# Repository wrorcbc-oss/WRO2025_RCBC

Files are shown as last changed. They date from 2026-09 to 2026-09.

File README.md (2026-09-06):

# WRO2026_RPRC
# 🚀 WRO 2026 Future Engineers – RPRC

<center>
<p align="center">
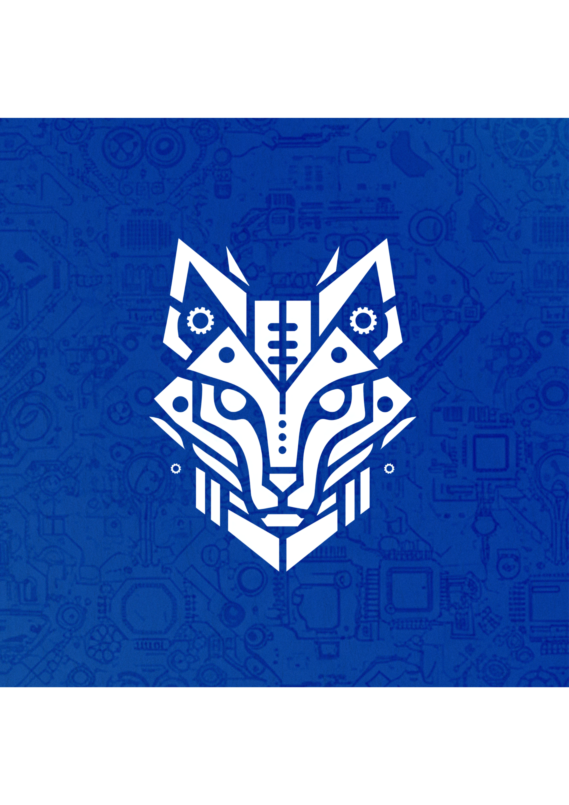
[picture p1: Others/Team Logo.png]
Team Logo
  
</p>


</center>

---

## **EGPYTIAN NATIONAL TEAM **

Welcome to the GitHub repository of Team RPRC, competing in the World Robot Olympiad™ (WRO®) Future Engineers 2025 category. Our team is made up of Egyptian students who have designed a compact, innovative, and autonomous self-driving vehicle to tackle the dynamic challenges of the WRO 2025 competition. Our team name, RPRC—which stands for Reliable Chassis, Brilliant Code—reflects our core philosophy: achieving perfect harmony between mechanical durability and highly intelligent software. This name signifies our competitive spirit, blending robust engineering with cutting-edge algorithms to push the boundaries of autonomous design.

Our mission was to engineer a highly precise and exceptionally fast autonomous vehicle for the WRO 2025 challenge, prioritizing dynamic stability, speed, and flawless execution over extreme miniaturization. Leveraging our expertise in electrical, mechanical, and software engineering, we optimized every component to dominate the 3 m x 3 m game field.
Current best times on the 3 m x 3 m field:
- **Open Challenge**: ## seconds (full score)
- **Obstacle Challenge**: ## seconds (full score)

---

## 📚 **Table of Contents**
- [📂 Complete Documentation Structure](#complete-documentation-structure)
- [👥 The Team](#the-team)
- [🎯 Challenge Overview](#challenge-overview)
- [🤖 Our Robot](#our-robot)
- [🔧 Electronic Systems](#electronic-systems)
- [⚙ Mechanical Systems](#mechanical-systems)
- [💻 Software Architecture](#software-architecture)
- [📹 Performance Videos](#performance-videos)
- [🌐 GitHub Utilization & Development](#github-utilization--development)
- [📜 License & Replication](#license--replication)

---

## 📂 **Complete Documentation Structure** 

## 🔍 **DETAILED TECHNICAL DOCUMENTATION AVAILABLE**

### **Each folder contains comprehensive README documentation with specialized technical content**

<div align="center">

<table>
  <thead>
    <tr>
      <th align="center">📁 Folder</th>
      <th align="center">🎯 Technical Content</th>
      <th align="center">📖 Detailed Documentation</th>
    </tr>
  </thead>
  <tbody>
    <tr>
      <td align="center"><b>⚙️ Mechanical_Design</b></td>
      <td align="center">
        <b>Mechanical Engineering</b><br>
        • 3D CAD designs<br>
        • Assembly instructions<br>
        • Gear system calculations
      </td>
      <td align="center">
        <a href="Mechanical_Design/README.md">🔗 Explore 3D Models & Assembly Documentation</a>
      </td>
    </tr>
    <tr>
      <td align="center"><b>🎨 colors</b></td>
      <td align="center">
        <b>Vision System Calibration</b><br>
        • Color space analysis<br>
        • Threshold optimization<br>
        • Lighting condition testing
      </td>
      <td align="center">
        <a href="colors/README.md">🔗 Explore Vision & Color Calibration Documentation</a>
      </td>
    </tr>
    <tr>
      <td align="center"><b>💾 software</b></td>
      <td align="center">
        <b>Software Algorithms</b><br>
        • Navigation logic<br>
        • Sensor fusion<br>
        • Control systems
      </td>
      <td align="center">
        <a href="software/README.md">🔗 Explore Software & Algorithms Documentation</a>
      </td>
    </tr>
    <tr>
      <td align="center"><b>📚 Others</b></td>
      <td align="center">
        <b>Technical References</b><br>
        • Component images<br>
        • Development resources<br>
        • Additional documentation
      </td>
      <td align="center">
        <a href="Others/README.md">🔗 Explore Additional Resources Documentation</a>
      </td>
    </tr>
  </tbody>
</table>

</div>

---

## 👥 **The Team** 

Team RPRC includes passionate students from EGYPT, guided by a coach. This is our **first year** competing in the WRO Future Engineers category, and each member brings unique skills to the project, from electronics to computer vision.

### Members
- **Yossef Hossam** (Team Leader)  
  *Role*: Electronics, Mechanical Design, Software, Strategy Integration  
  *Background*: High School Student, STEM October High School For Boys (S28)  
  *Contact*: [YossefHossam1230@gmail.com](mailto:YossefHossam1230@gmail.com), [Youssef1025130@stemoctober.moe.edu.eg](mailto:Youssef1025130@stemoctober.moe.edu.eg)
  *Born*: 2009, Egypt
  
- **Mahmoud Atef**  
  *Role*: Computer Vision Research, Strategy  
  *Background*: High School Student, STEM October High School For Boys (S28)  
  *Born*: 2010, Egypt
  *Contact* [mahmoudatef12534@gmail.com](mailto:mahmoudatef12534@gmail.com), [mahmoud.1025119@stemoctober.moe.edu.eg](mailto:mahmoud.1025119@stemoctober.moe.edu.eg)  
  
- **Hamza Mahmoud**
  *Role*: Electronics, Software  
  *Background*: High School Student, STEM October High School For Boys (S28)  
  *Contact*: [Hamza.1025140@stemoctober.moe.edu.eg](mailto:Hamza.1025140@stemoctober.moe.edu.eg) 
  *Born*: 2009, EGYPT

### Coach
- **Manar**  
  *Role*: Team Coach, Connector  
  *Background*: Graduated, Computer and Informatics Science, Ain Shams University  
  *Born*: 2000, EGYPT
  
<br>
<div align="center">
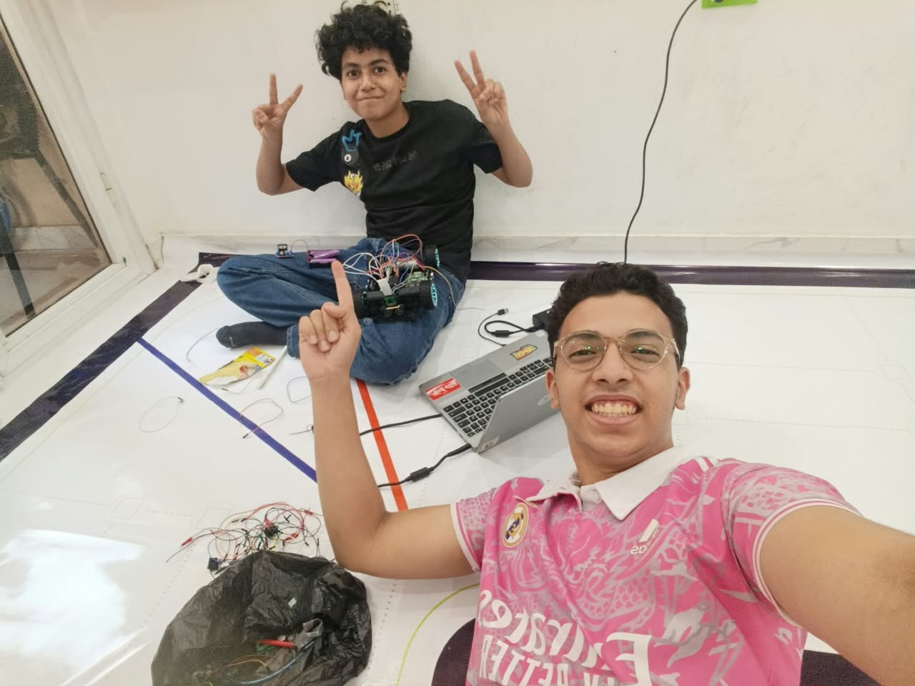
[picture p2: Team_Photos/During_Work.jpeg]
Team RCBC Fun Photo
  
</div>

### **Team Journey Moments**
Throughout our development process from initial concept to competition readiness, we captured key moments demonstrating our collaborative spirit and technical dedication. These images showcase our brainstorming sessions, technical adjustments, and competition preparation.
---

## 🎯 **Challenge Overview** 

<div align="center">

## 🏁 **WRO 2026 Future Engineers Challenges**

### **Two distinct autonomous navigation challenges testing vehicle intelligence and precision**

</div>

### **🚀 Open Challenge**
<div align="center">

**Objective**: Complete three autonomous laps on dynamically configured tracks

| Aspect | Challenge | Our Solution |
|---|---|---|
| **Track Variability** | Random internal wall placements | Adaptive path planning algorithms |
| **Navigation** | Unknown track layouts each round | Robust wall-following with corner detection |
| **Performance** | Consistent lap times across variations | Optimized PID control and sensor fusion |
| **Precision** | Maintain course in narrow lanes | High-accuracy steering and speed control |

</div>

### **🚧 Obstacle Challenge**
<div align="center">

**Objective**: Navigate three laps with traffic sign compliance and precision parking

| Challenge Element | Requirement | Our Implementation |
|---|---|---|
| **Traffic Signs** | Red → Right bias<br>Green → Left bias | Real-time color detection with LAB colorspace |
| **Obstacle Avoidance** | Dynamic path adjustment | Smooth following at consistent distances |
| **Parking Maneuver** | Parallel parking after lap completion | Multi-stage parking with sensor validation |
| **Navigation** | Shortest path optimization | Efficient routing around obstacle combinations |
</div>

### **📁 Documentation Evaluation Framework**

<div align="center">

## 📊 **WRO 2026 Engineering Documentation Scoring (30 points total)**

| Scoring Area | Maximum Points | Our Documentation Coverage |
|---|---|---|
| **1. Mobility Management** | 4 points | Complete mechanical design, motor selection, steering system, assembly instructions |
| **2. Power & Sense Management** | 4 points | Power systems, sensor integration, wiring diagrams, component specifications |
| **3. Obstacle Management** | 4 points | Navigation algorithms, parking strategies, source code with detailed comments |
| **4. Pictures – Team and Vehicle** | 4 points | Multi-angle vehicle photos, team photos, component labeling |
| **5. Performance Videos** | 4 points | Complete challenge demonstrations with commentary and analysis |
| **6. GitHub Utilization** | 4 points | Version control, structured documentation, regular commits |
| **7. Engineering Factor** | 4 points | Custom design and manufacturing throughout the vehicle |
| **8. Overall Judge Impression** | 2 points | Clear communication enabling easy replication |
| **Total Documentation Score** | **Still unknown (WE Haven't Competed Yet** | **(≈25% of total competition score)** |
</div>

### **Key Evaluation Areas**
- Still Unknown ( WE will Update all These Areas After The Competion )

**Scoring Philosophy**: Documentation is evaluated based on completeness, structure, and ease of replication - not comparison between teams. Each scoring area uses a 0-4 point scale where "Exceeds Expectations" requires not only enabling exact duplication but also providing improvement suggestions.

### **🎓 Educational Objectives**
- **Advanced Computer Vision**: Real-world implementation of color space theory
- **Sensor Fusion**: Integrating multiple data sources for robust navigation
- **Control Systems**: Precision steering and speed control algorithms
- **Engineering Documentation**: Professional technical communication
- **Problem Solving**: Systematic approach to technical challenges

---

## 🤖 **Our Robot** 

<div align="center">
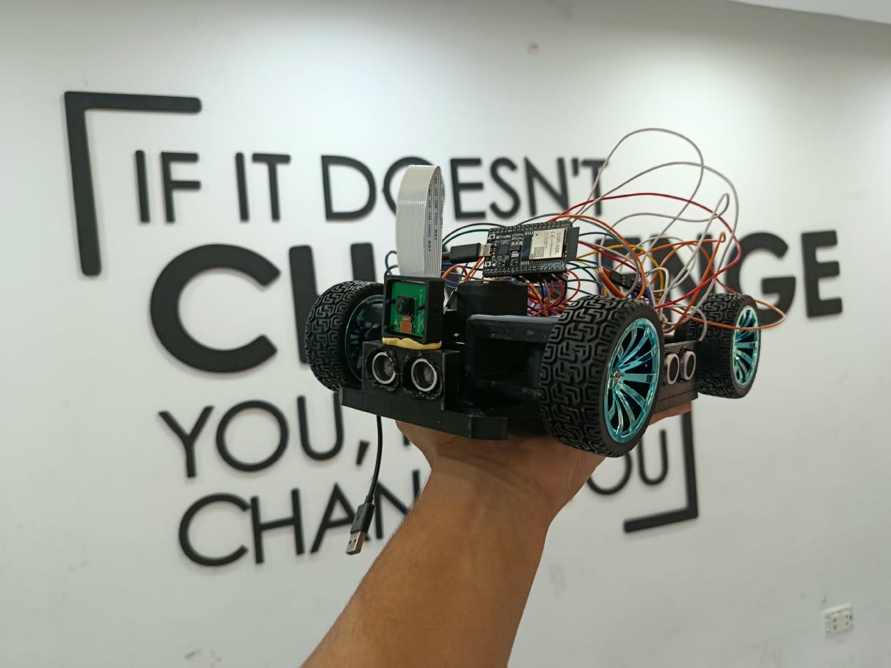
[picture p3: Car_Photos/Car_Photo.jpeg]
RCBC Autonomous Vehicle
  
</div>

Our platform represents a breakthrough in high-performance autonomous vehicle design, achieving exceptional speed and pinpoint precision without compromising dynamic stability. The complete system seamlessly integrates a robust custom mechanical chassis with sophisticated electronics and highly optimized software algorithms

**Core Processing Architecture**:
- **Primary Vision Processor**: Rasberry Pi 4 model B dedicated to real-time image processing
- **Secondary Sensor Processor**: Esp32 microcontroller handling multi-sensor data fusion
- **Distributed Processing**: Optimized task allocation between vision and control subsystems

**Perception System**:
- **Front-Facing Detection**: HC-SR04 Ultrasonic Sensor Detector for general obstacle awareness
- **Side-Mounted Precision Sensors**: Dual HC-SR04 Ultrasonic Sensor Detector for parking detection
- **Visual Navigation**: Rasberry Pi Camera module 2 8MP camera with optimized field of view for track following and obstacle detection

**Propulsion and Control**:
- **Drive System**: 450 RPM DC Gear Motor JGA25-370 with External encoder feedback
- **Steering Mechanism**: Custom Ackermann geometry with metalic servo actuation
- **Power Management**: Integrated LiPo Batteries with comprehensive power distribution

Complete vehicle documentation with detailed component identification available in [vehicle photos](Car_Photos/README.md)

<div align="center">
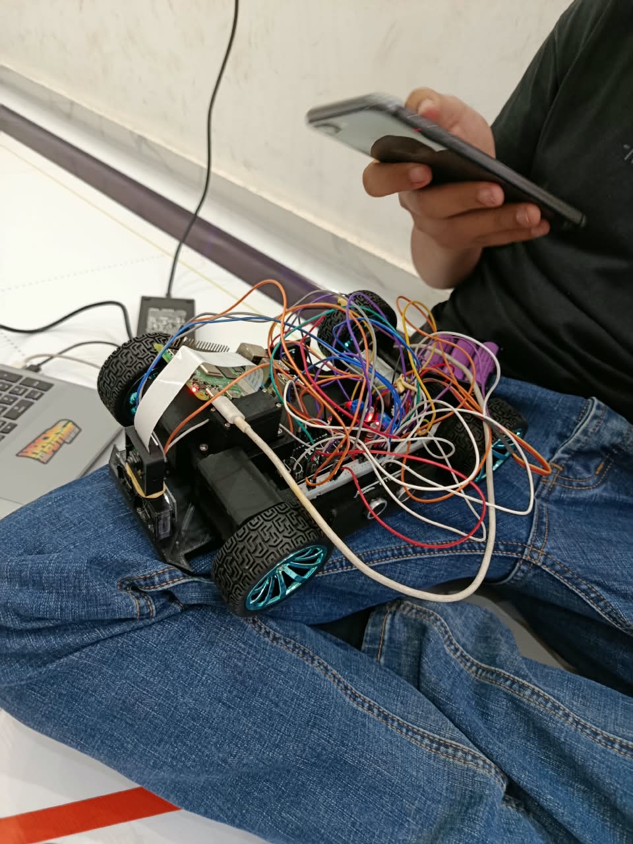
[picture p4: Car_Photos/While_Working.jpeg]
Digital to Physical Realization
  
</div>

### Potential Future Improvements (Overall Vehicle)
- Reduce size even further to ≈ 100 × 150 × 60 mm by switching to smaller LiPo (3.7 V), a coreless motor + micro gearbox and smaller mechanic differential style.
- Implement four-wheel steering or active rear-axle 4 wheel drive to control for tighter turning radius on narrow lanes.
- Add a very small extra second camera facing backwards for reverse parking or emergency obstacle detection.

---

## 🔧 **Electronic Systems** 

Our electronic architecture emphasizes modularity, reliability, and hands-on engineering through custom manufacturing approaches.

### **Component Integration Strategy**

<div align="center">

| Component | Image | Quantity | Function | Key Specifications |
|---|---|---|---|---|
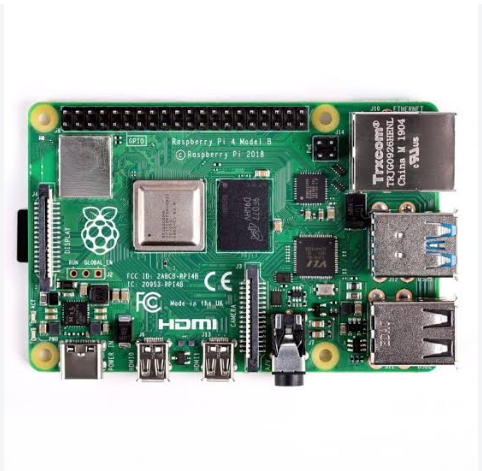
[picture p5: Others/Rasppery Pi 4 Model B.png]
Raspberry Pi 4
| **Raspberry Pi 4 Model B (4GB)** |  | 1 | Main Processing & Vision | Quad-core Cortex-A72, 4GB RAM, Peripheral & Camera Interface |
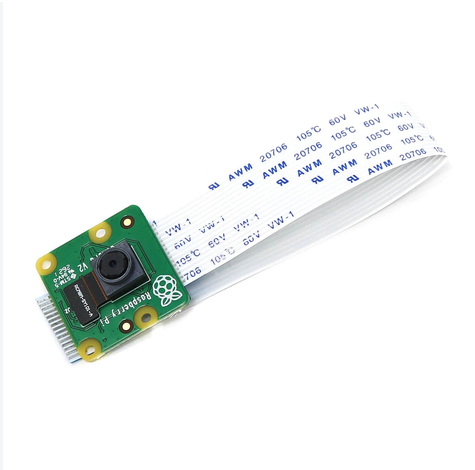
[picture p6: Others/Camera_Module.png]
Camera Module
| **Raspberry Pi Camera Module 2 (8MP)** |  | 1 | Visual Navigation | 8MP Sony IMX219 sensor, 1080p video, CSI interface |
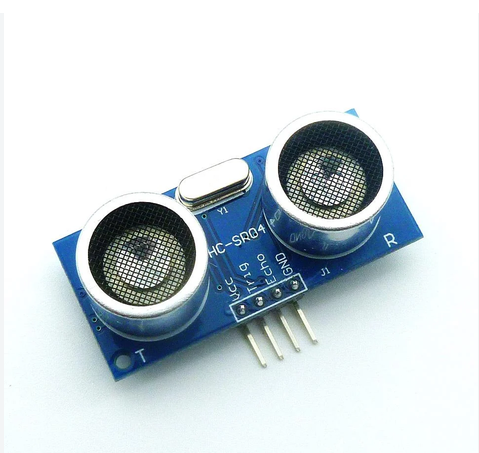
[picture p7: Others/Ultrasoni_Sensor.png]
Ultrasonic Sensor
| **HC-SR04 Ultrasonic Sensor** |  | 2 | Distance & Obstacle Detection | 2cm to 400cm range, 15-degree measurement angle |
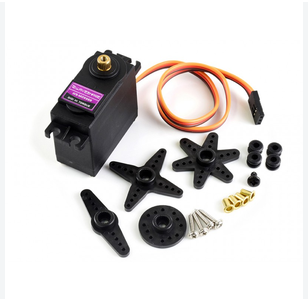
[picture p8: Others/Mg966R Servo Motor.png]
Servo Motor
| **MG966R Servo Motor** |  | 1 | Steering Actuation | High-torque metal gear servo, 180° rotation |
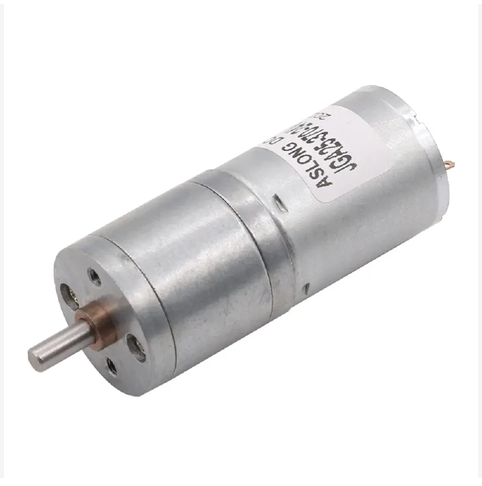
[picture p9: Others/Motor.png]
Motor Driver
| **L298N Motor Driver** |  | 1 | Motor Control | Dual H-bridge driver, up to 2A current per channel |
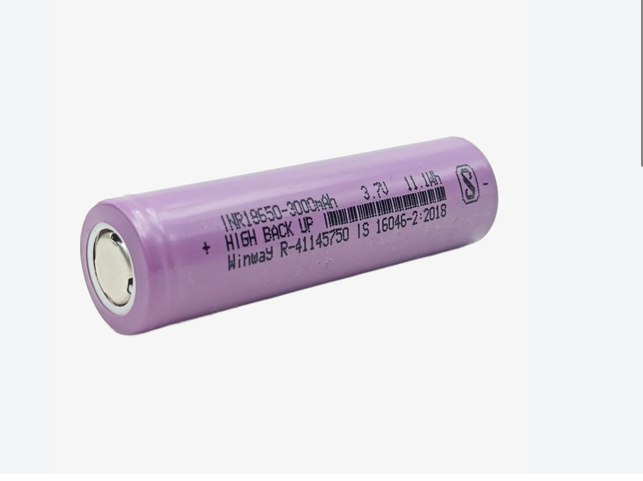
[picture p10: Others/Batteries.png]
LiPo Battery
| **LiPo Battery Pack** |  | 1 | Power Source | High-capacity rechargeable lithium polymer power supply |

**Component Selection Philosophy**: We prioritize widely available, well-documented components to ensure reproducibility. All parts can be sourced through standard electronics distributors using the provided specifications and images.

### **Professional Wiring Implementation**

<div align="center">
  <a href="schemes/wiring_diagram.jpg" target="_blank"> 
    Professional Wiring Diagram
  </a>
  Physical Implementation
</div>
<p align="center">
  <em>1) Complete hand-drawn and digitally traced professional wiring schematic showing all electrical connections (<a href="schemes/wiring_diagram.jpg" target="_blank">view full resolution</a>) • 2) Physical implementation demonstrating socket-based construction of the schematic</em>
</p>

### **Individual Component Schematics**

<div align="center">

<div align="center">

| Component Schematic | Description | Full Documentation |
|---|---|---|
| Raspberry Pi Wiring | **Raspberry Pi 4 Connection System**<br>GPIO interface, power distribution, and camera CSI connection | [View Details](schemes/README.md#microcontroller-systems) |
| Driver Scheme | **L298N Motor Driver Control**<br>PWM motor regulation and dual H-bridge connections | [View Details](schemes/README.md#motor-control-systems) |
| Servo Scheme | **MG966R Servo Control**<br>Steering mechanism PWM signal mapping | [View Details](schemes/README.md#motor-control-systems) |
| Ultrasonic Scheme | **HC-SR04 Ultrasonic Sensor Network**<br>Trigger and echo pin integration for distance measurement | [View Details](schemes/README.md#sensor-systems) |
| Power Scheme | **Power Management & Distribution**<br>LiPo battery charging and main power regulation | [View Details](schemes/README.md#power-management-components) |
| Button Scheme | **User Interface & Control**<br>Start push button and tactile system interface | [View Details](schemes/README.md#-interface--control-systems) |
</div>

### **Power Management Innovation**

During system integration, we identified a critical design limitation in our chosen power management IC. The LiPo Rider Plus's switch only controlled the 5V output rail, leaving the 3.3V regulator permanently active and creating potential battery drain.

**Engineering Solution**:
* **Root Cause Analysis**: Direct battery routing to auxiliary components bypassing the main control switch, causing minor standby current draw.
* **Component Modification**: Remapped power distribution lines and integrated a reliable master power distribution path.
* **Implementation**: Rerouted the main input rails through the primary hardware switch to ensure complete circuit isolation when deactivated.
* **Validation**: Full power cut-off achieved with zero standby current draw, protecting the Raspberry Pi and motor drivers from unwanted power leakage.
<div align="center">
  Power Management Modification
  <p><em>Hardware modification enabling complete power rail control through single switch</em></p>
</div>

### **Signal Integrity Systems**

The **LM2569 Buck converter** ensures reliable communication between our 3.3V microcontrollers and 5V servo system. This implementation prevents signal degradation and ensures precise servo positioning under all operating conditions.

### **Thermal Performance Validation**

Comprehensive thermal analysis confirmed optimal operating temperatures across all critical subsystems:

### **Sensor Integration Challenges**

Our minimal vertical profile created unique challenges for Time-of-Flight sensor implementation. The proximity to ground plane caused premature ground intersection in the sensors' field of view, limiting effective detection range.

**Optical Solution**:
- **Angular Adjustment**: Upward sensor tilt to delay ground intersection
- **Optical Modification**: Custom window lenses to narrow field of view
- **Performance Improvement**: Extended usable detection range from ~150cm to ~300cm

### **Development Convenience Features**

Implementation of magnetic USB connectors for programming interfaces significantly improved development workflow efficiency, allowing rapid code iterations without physical connector wear.

<div align="center">
Development Interface Access
<p><em>Easy-access programming interface with magnetic connection system</em></p>
</div>

### **Performance Specifications**

- **Maximum Theoretical Speed**: 1.52 m/s (calculated from motor RPM and drive train ratios)
- **Operational Speed**: 1.4 m/s (PWM controlled for stability optimization)
- **Battery Endurance**: 3-4 hours typical operation
- **Charge Duration**: ~60 minutes via USB-C fast charging
- **Power Consumption**: 0.8W minimum, 200-250mA typical operational current

### Powertrain – Potential Improvements
- Switch to higher RPM coreless motor + greater 25:1 Micro Metal Gearbox → theoretical top speed > 2.3 m/s while keeping the same design.
- Replace the 25:25 external gear with an internal planetary stage inside the JGA27-370 motor can → saves 4 mm length with direct mounting of the motor to the rear axle.
- Active cooling (micro 10 mm fan, 0.8 g) → could improve the overall airflow in the system, allowing for faster operation and even higher stability.

---

## ⚙ **Mechanical Systems** 

Our mechanical design philosophy centers on achieving maximum capability within minimal dimensions through innovative engineering and precision manufacturing.

### **Core Mechanical Specifications**
- **Overall Dimensions**: 250mm (L) × 180mm (W) × 70mm (H)
- **Total Mass**: Approximately 800 grams
- **Structural Material**: 3D-printed PLA+ for optimal strength-to-weight ratio
- **Drive Configuration**: Rear-wheel drive with custom differential
- **Steering System**: True Ackermann geometry with precision linkage

### **Design Integration Approach**

<div align="center">
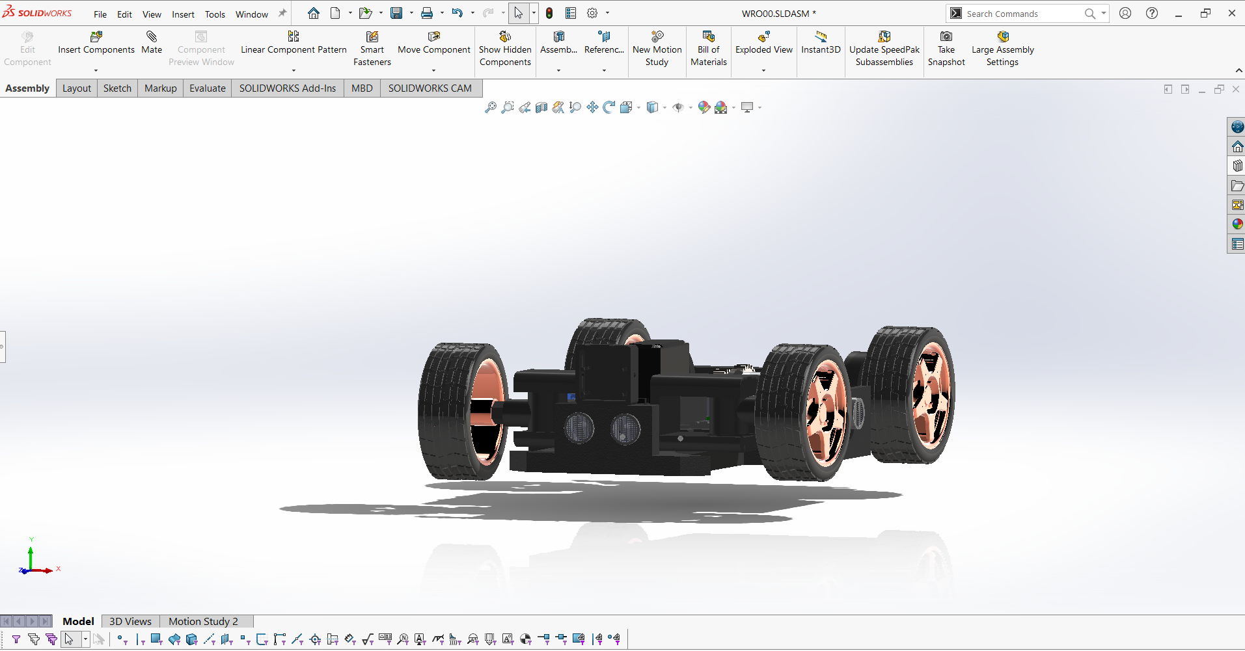
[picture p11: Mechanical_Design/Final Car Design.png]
Digital Design Model

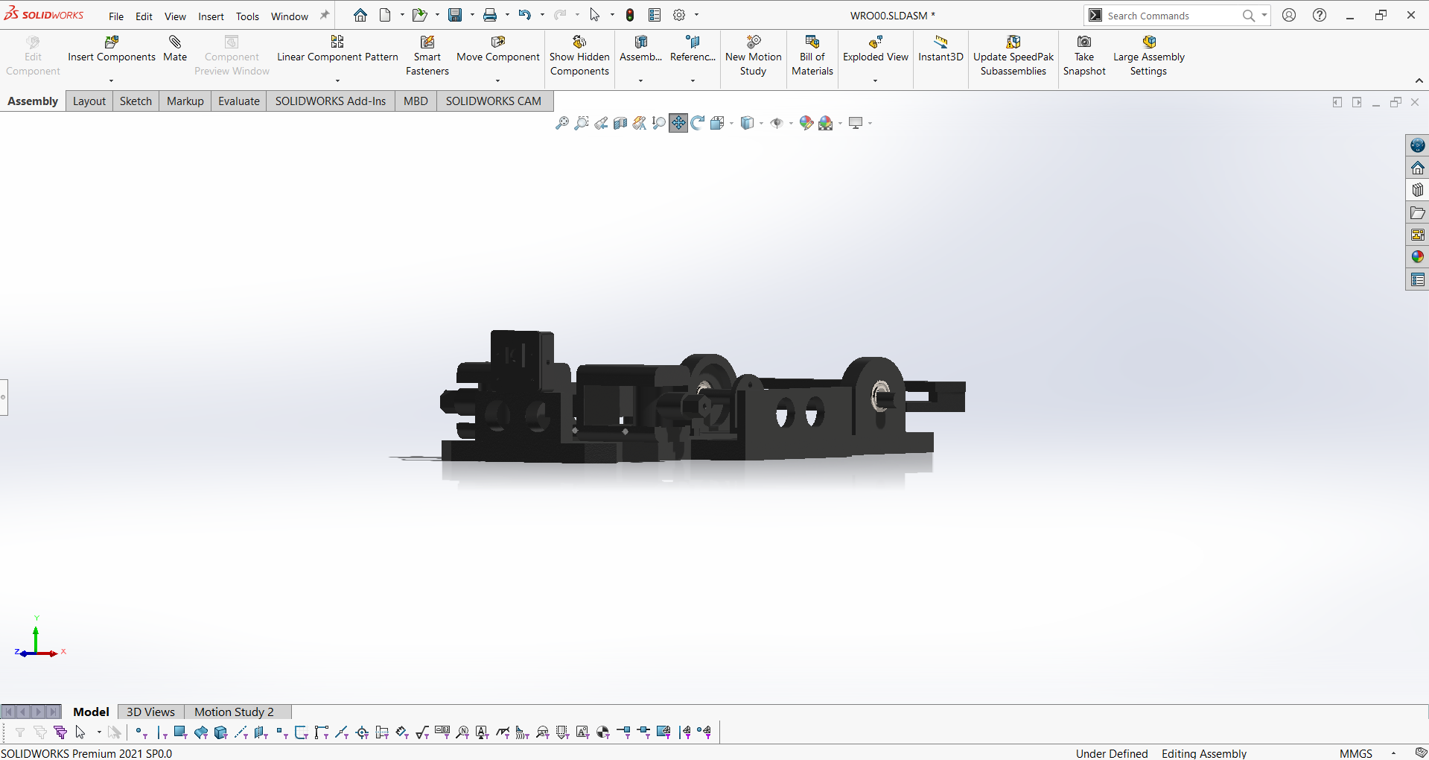
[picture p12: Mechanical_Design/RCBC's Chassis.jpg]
Physical Implementation

</div>
<p align="center">
  <em>Digital design precision translated to physical implementation through advanced manufacturing techniques</em>
</p>

### **Steering Geometry Implementation**

Our custom Ackermann steering system ensures each wheel maintains optimal alignment during turns, minimizing tire scrub and maximizing maneuverability.

<div align="center">
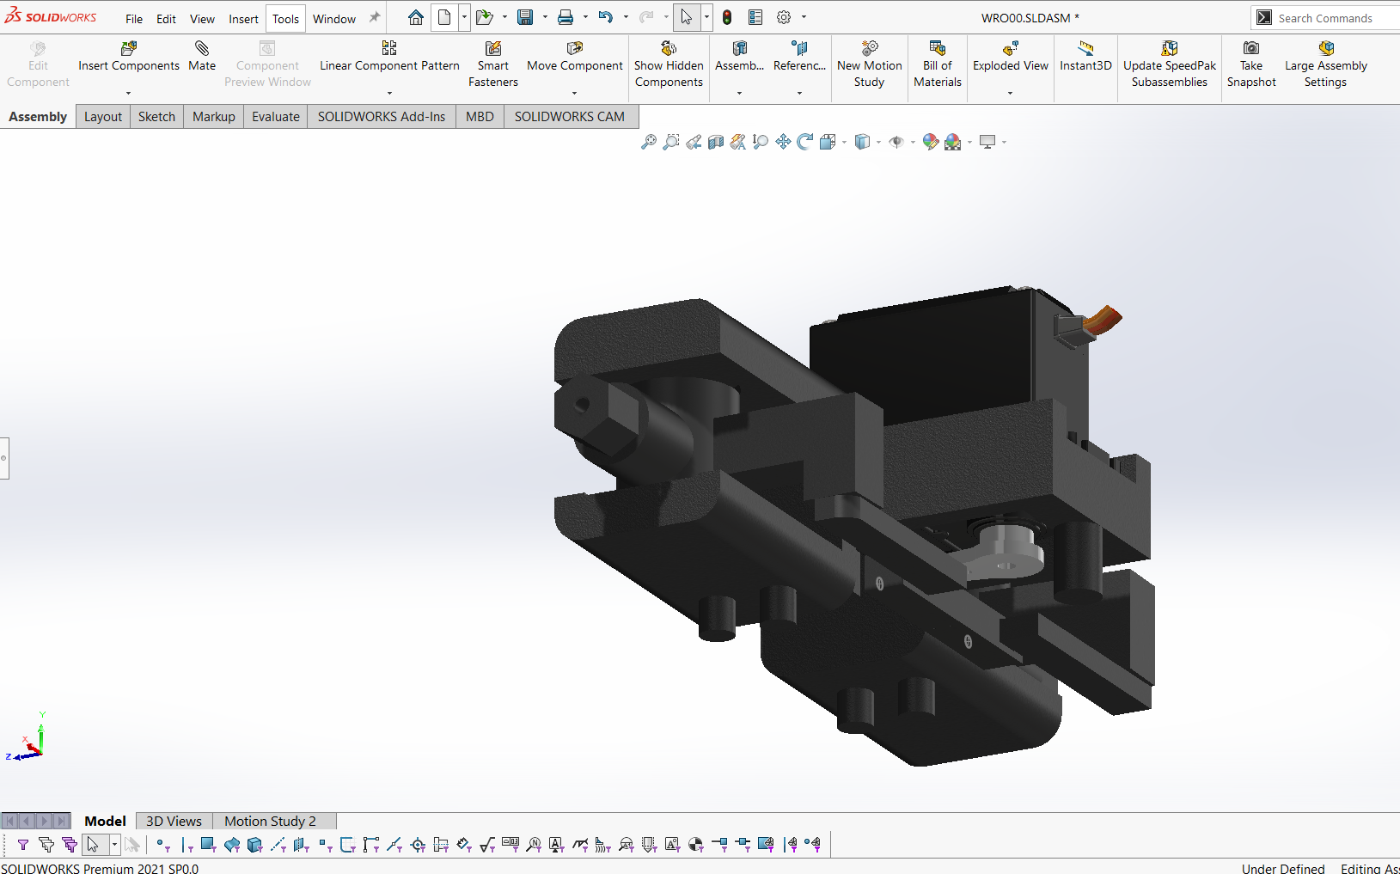
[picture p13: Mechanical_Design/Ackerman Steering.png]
Steering Mechanism Animation

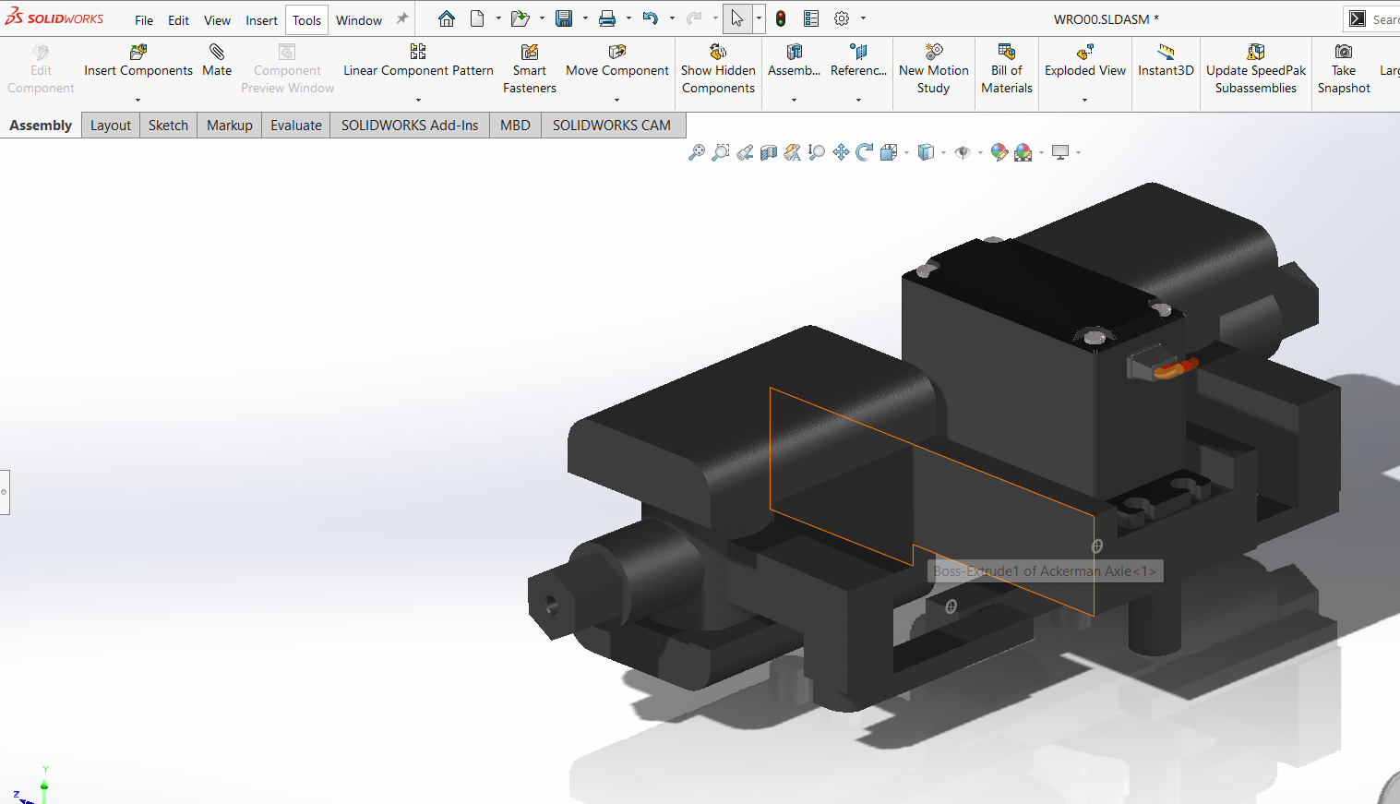
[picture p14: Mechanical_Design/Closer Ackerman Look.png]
Steering Geometry Analysis

</div>

<p align="center">
  <em>Dynamic steering simulation and geometric analysis ensuring optimal turning performance</em>
</p>

**Steering System Evolution**:
- **Initial Concept**: Integrated print-in-place mechanism for rapid prototyping
- **Performance Refinement**: Multi-component assembly for long-term precision
- **Final Implementation**: Four M2 fasteners with locking nuts for permanent alignment
- **Wheel Articulation**: -50° to +32° range optimized for competition track dimensions

### Mechanical – Potential Improvements
- True Ackermann geometry.
- Ball bearings on the two rear wheels → theoretical 7–9 % less rolling resistance in CAD tests.
- Possible uspension system using micro torsion bars could improve stability if the track includes ground obstacles in the future when crossing the 3 mm track.

### **Power Transmission System**

The custom 2-gear differential ensures smooth torque distribution during turning maneuvers, preventing wheel slip and maintaining traction.
<div align="center">
<table align="center">
<tr>
<td align="center">
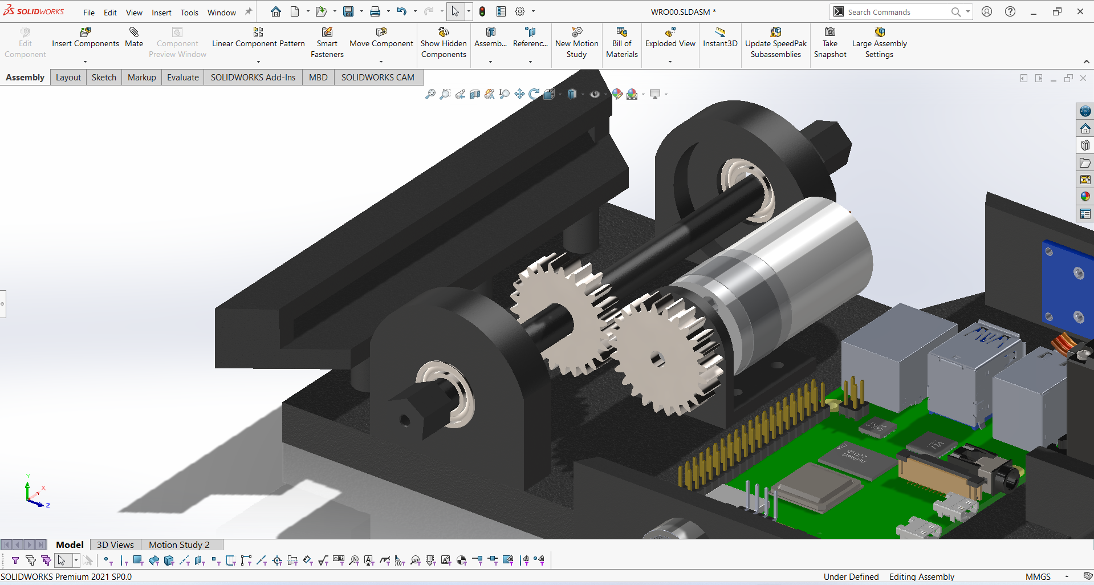
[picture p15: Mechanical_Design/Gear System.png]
Gear System Test

</td>
<td align="center">
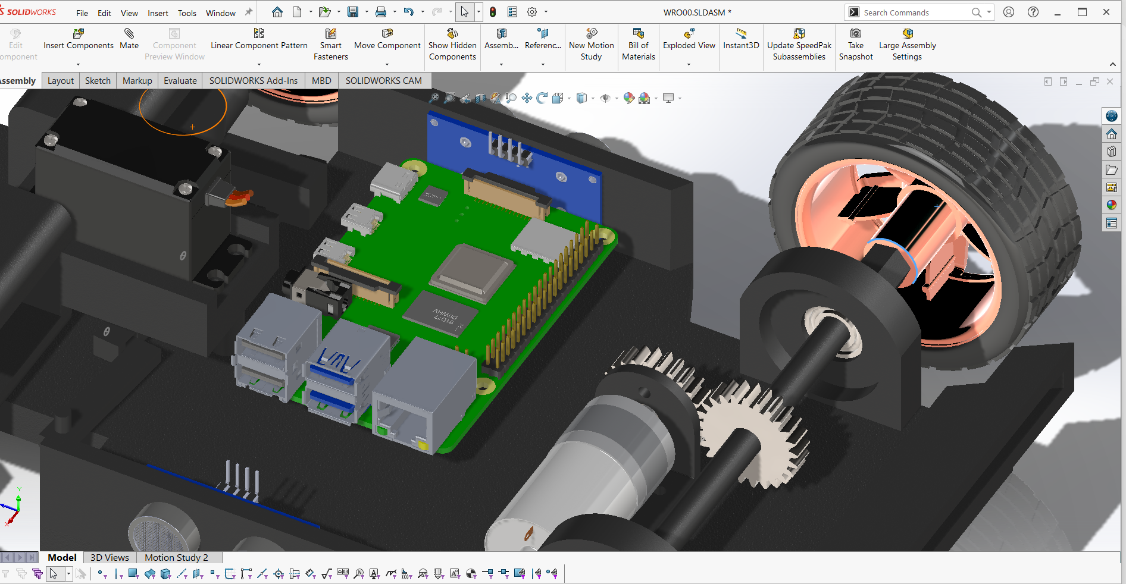
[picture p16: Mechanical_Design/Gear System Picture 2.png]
Gear Assembly View 1
<br>
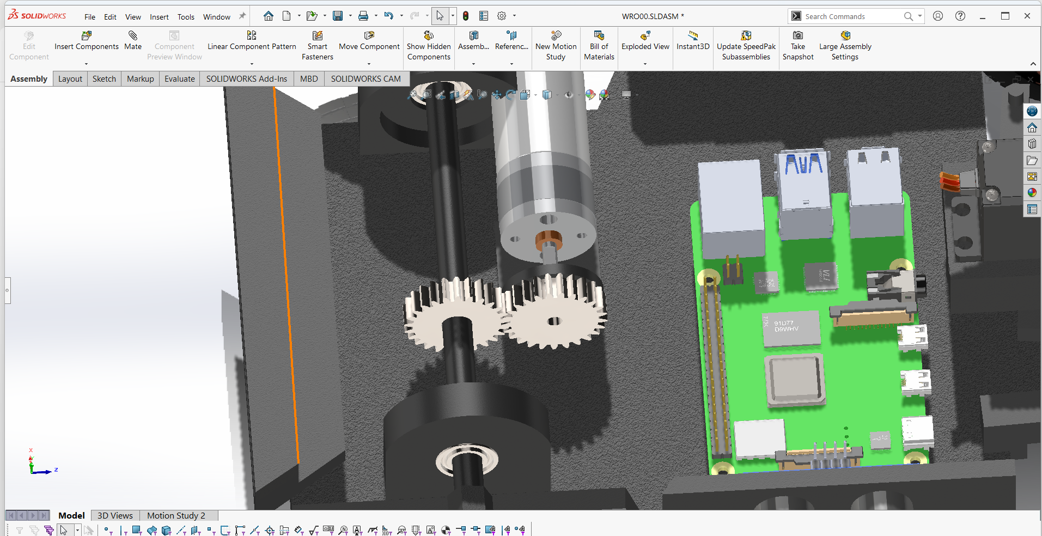
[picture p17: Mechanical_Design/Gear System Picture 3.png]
Gear Assembly View 2

</td>
</tr>
</table>
</div>
<p align="center">
  <em>Physical validation of drive transmission operation and comprehensive CAD documentation</em>
</p>

<div align="center">

**Gear System Architecture**:
- **Speed Reduction**: 25:25 ratio through custom spur gear design
- **Torque Distribution**: Two 25-tooth spur gears enabling independent wheel rotation transferring the torque direct from the motor.
- **Manufacturing Precision**: 100% infill for maximum durability under load
- **Efficiency Optimization**: Precisely calculated tooth profiles for minimal power loss

### **Manufacturing File Repository**

*All components provided in 3MF format for maximum compatibility across different 3D printing platforms and slicing software*

<div align="center">

| Component | File Reference | Quantity | Visual Reference | Functional Description |
|---|---|---|---|---|
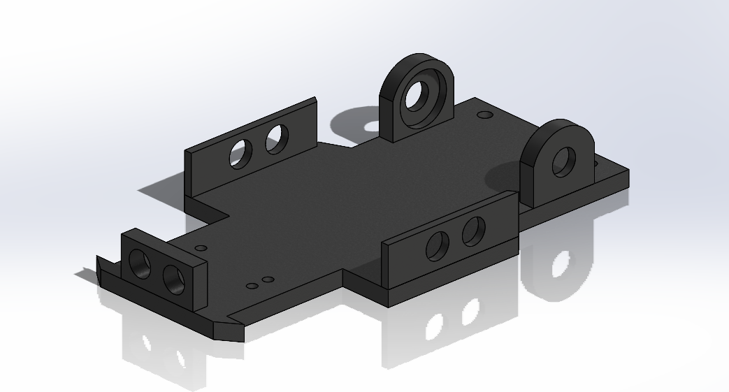
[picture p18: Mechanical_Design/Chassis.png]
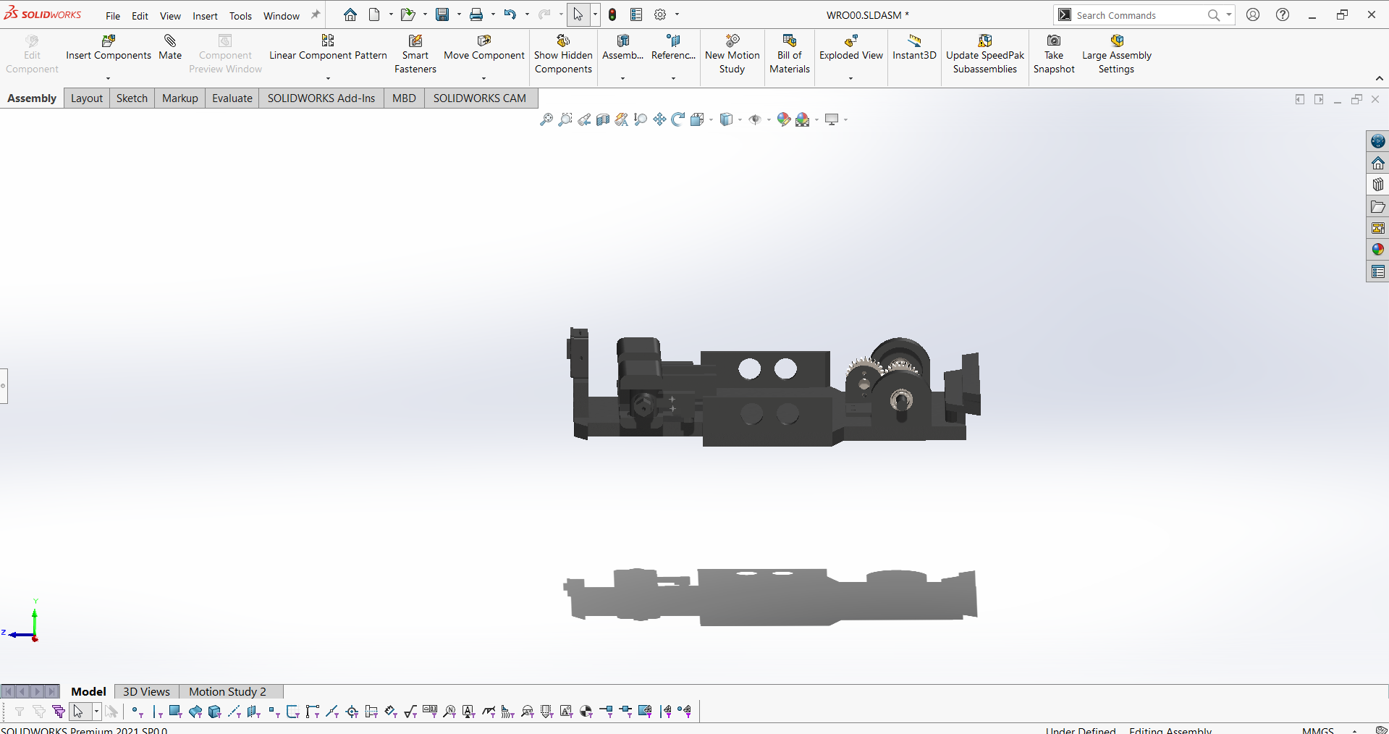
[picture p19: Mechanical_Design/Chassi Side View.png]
| **Main Chassis** | [`RCBC Chassis.3MF`](Mechanical_Design/RCBC%20Chassis.3MF) | 1 |  | Primary structural element with integrated mounting features |
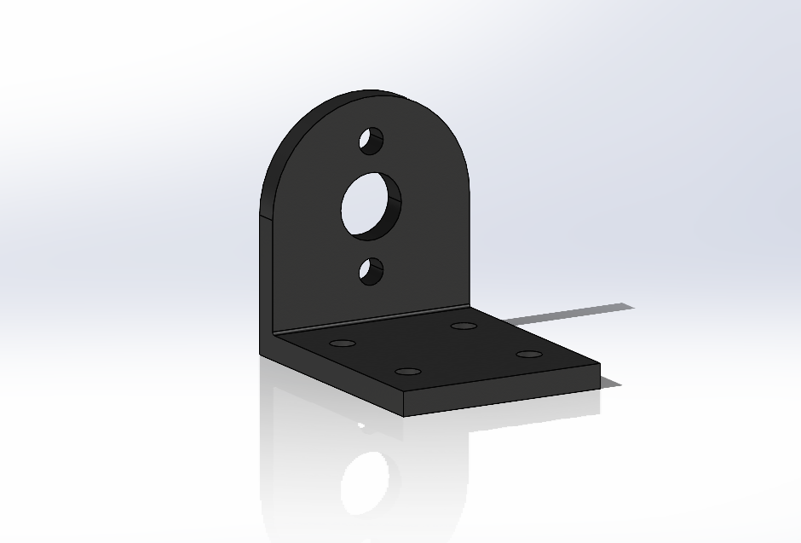
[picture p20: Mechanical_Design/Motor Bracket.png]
| **Motor Bracket** | [`JGA25-370 motor bracket.step.3MF`](Mechanical_Design/JGA25-370%20motor%20bracket.step.3MF) | 1 |  | Mounting bracket specifically designed for JGA25-370 motor |
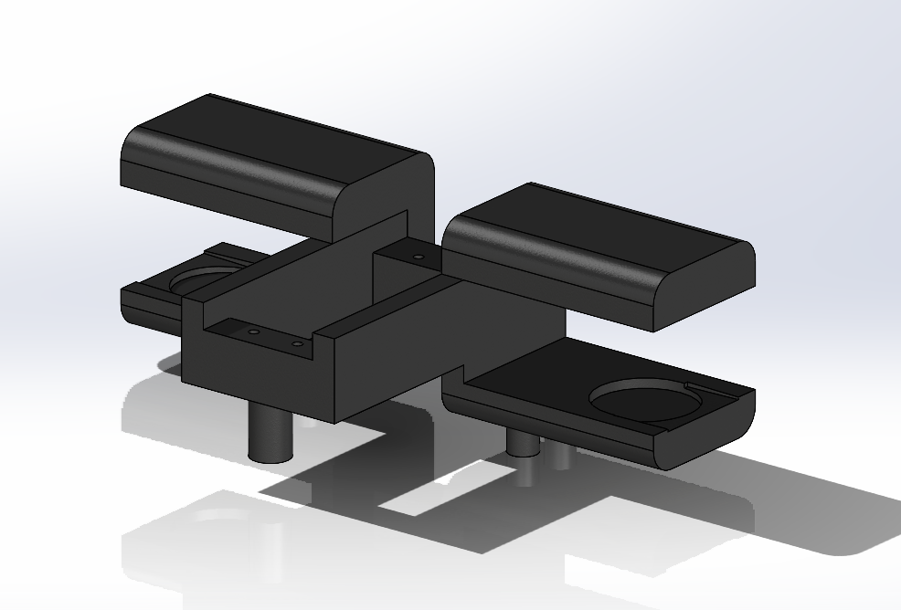
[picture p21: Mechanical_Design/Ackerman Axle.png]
| **Ackerman Axle** | [`Ackerman Axle.3MF`](Mechanical_Design/Ackerman%20Axle.3MF) | 1 |  | Main steering linkage for Ackermann geometry |
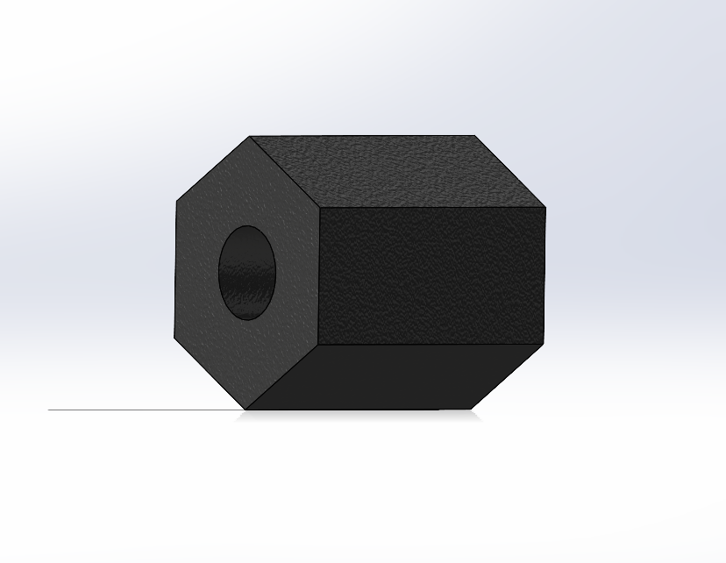
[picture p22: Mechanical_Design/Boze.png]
| **Knuckle Joint** | [`Knuckle_Joint_boze.3MF`](Mechanical_Design/Knuckle_Joint_boze.3MF) | 2 |  | Steering knuckle joints for front wheels |
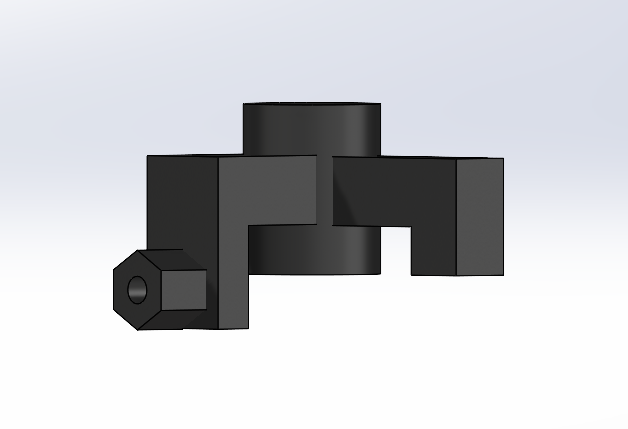
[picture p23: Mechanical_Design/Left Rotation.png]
| **Rotation Left** | [`Rotation_Left.3MF`](Mechanical_Design/Rotation_Left.3MF) | 1 |  | Left side steering rotation component |
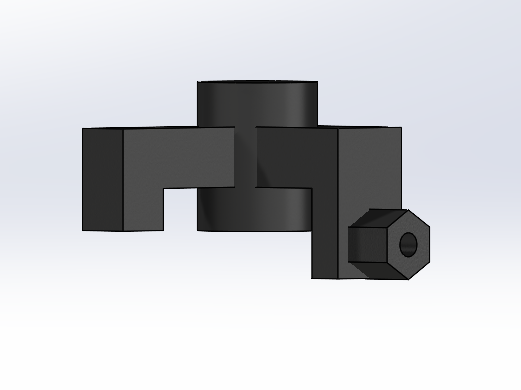
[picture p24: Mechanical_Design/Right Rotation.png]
| **Rotation Right**| [`Rotation_Right.3MF`](Mechanical_Design/Rotation_Right.3MF) | 1 |  | Right side steering rotation component |
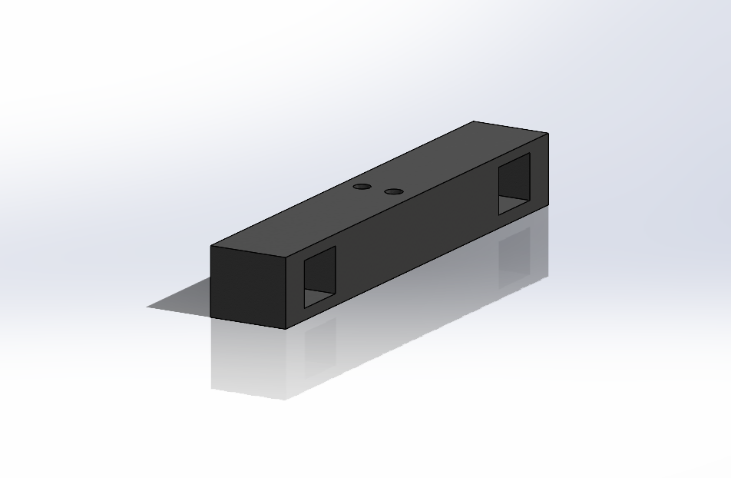
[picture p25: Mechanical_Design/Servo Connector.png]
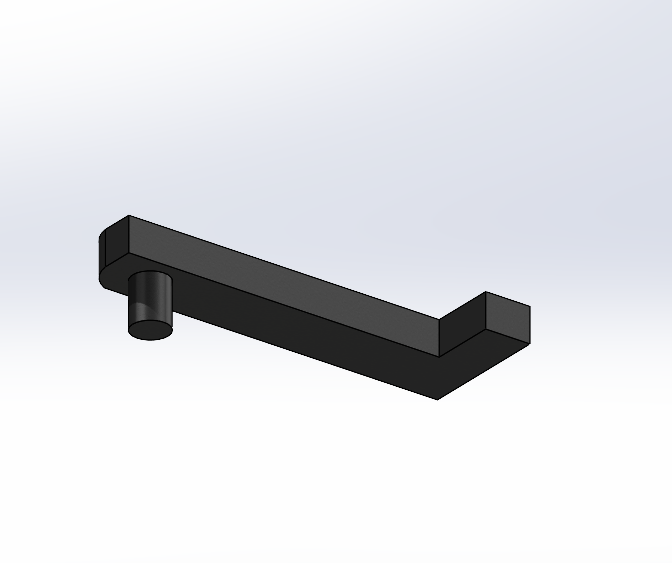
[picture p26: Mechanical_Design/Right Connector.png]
| **Servo Connector** | [`Servo_Connector.3MF`](Mechanical_Design/Servo_Connector.3MF) | 1 |  | Linkage connecting the steering servo to the axle |
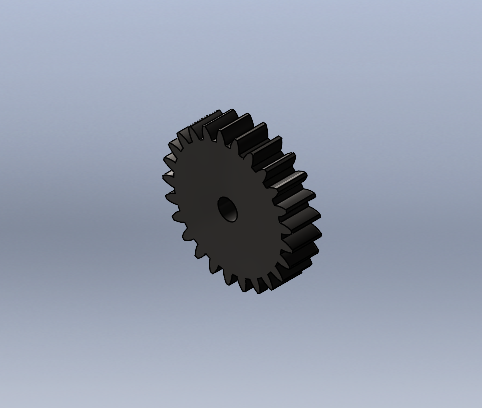
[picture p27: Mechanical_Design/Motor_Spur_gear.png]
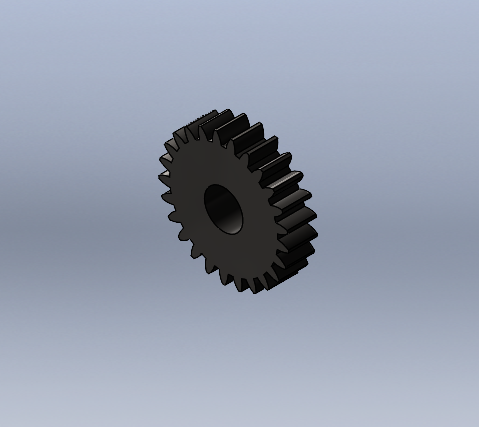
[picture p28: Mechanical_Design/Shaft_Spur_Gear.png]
| **Spur Gear** | [`spur gear_am.3MF`](Mechanical_Design/spur%20gear_am.3MF) | 1 |  | Main torque transmission spur gear |
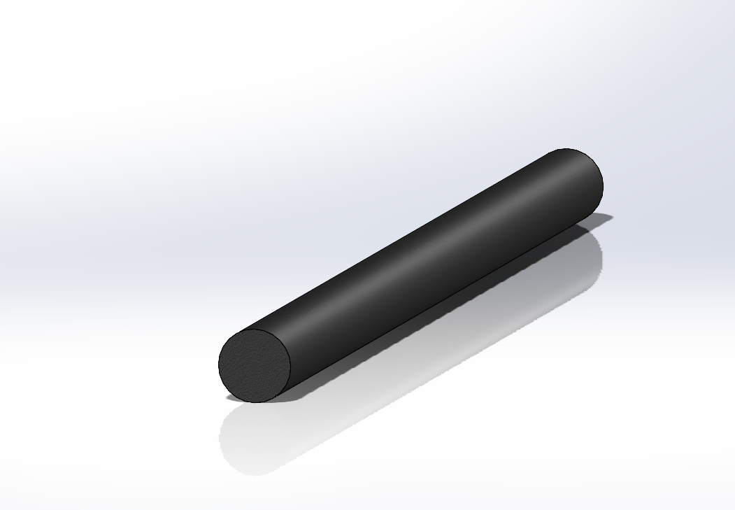
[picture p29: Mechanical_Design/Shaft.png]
| **Drive Shaft** | [`Shaft.3MF`](Mechanical_Design/Shaft.3MF) | 1 |  | Main mechanical drive transmission shaft |
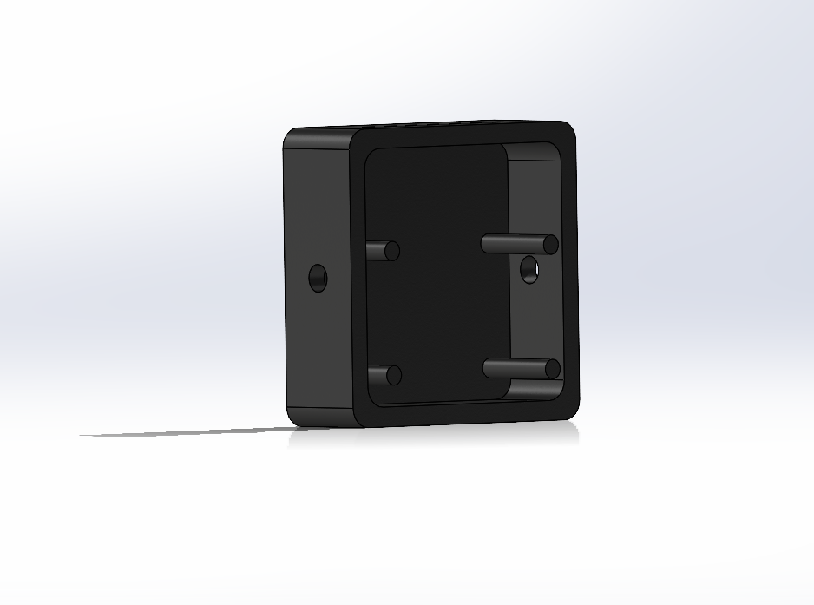
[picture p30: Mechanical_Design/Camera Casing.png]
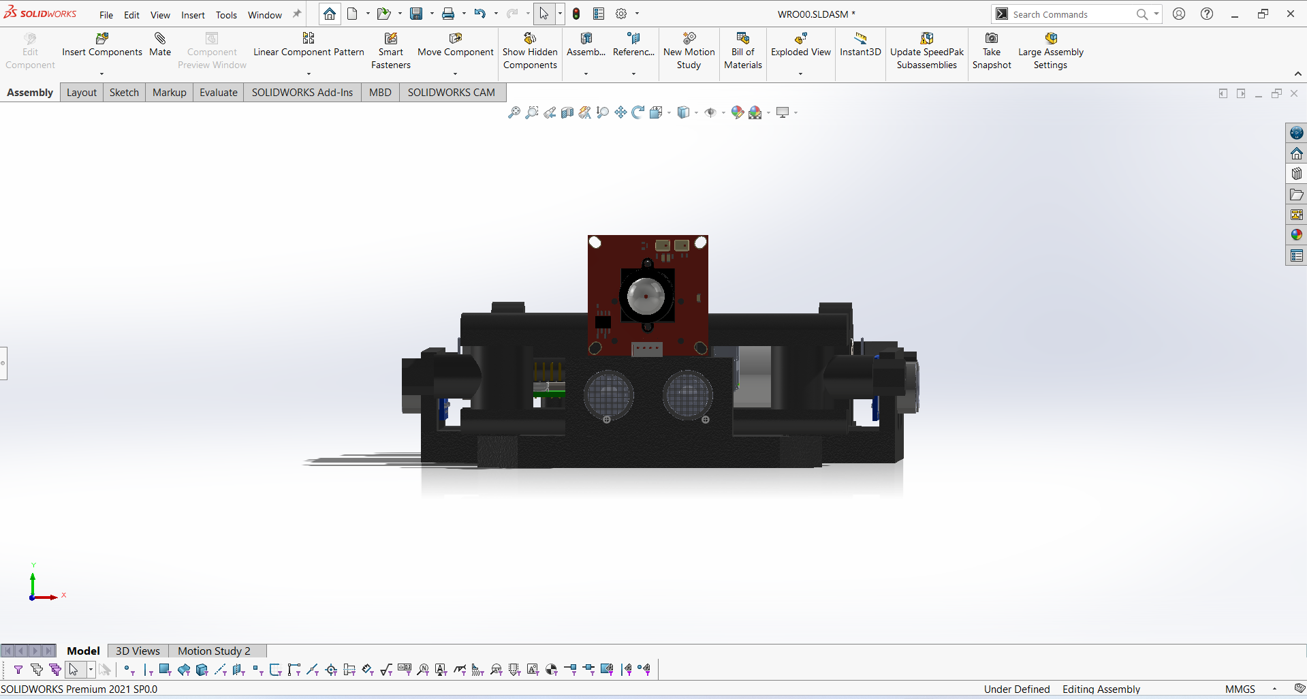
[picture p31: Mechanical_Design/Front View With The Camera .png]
| **Camera Casing** | [`camera casing 1.3MF`](Mechanical_Design/camera%20casing%201.3MF) | 1 |  | Enclosure and protection for the vision system |
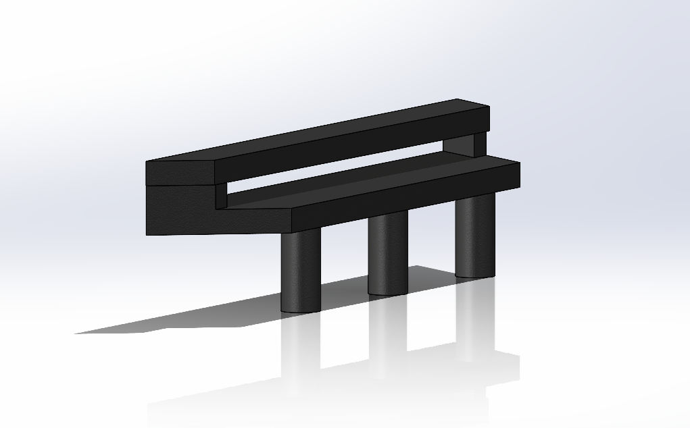
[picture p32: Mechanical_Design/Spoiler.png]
| **Rear Spoiler** | [`spoiler.3MF`](Mechanical_Design/spoiler.3MF) | 1 |  | Aerodynamic rear spoiler structure |

</div>

### **Performance Engineering Analysis**

**Drive Train Calculations**:
- **Motor Specification**: 450 RPM JGA 25-370 DC motor with quadrature encoder
- **Gear Reduction**: 25:25 ratio providing optimal speed-torque balance
- **Theoretical Maximum Velocity**: 1.52 m/s derived from wheel geometry and drive ratios
- **Operational Velocity**: 1.5 m/s selected for optimal control stability

**Structural Analysis**:
- **Motor Torque Capacity**: ~1.25 Nm at 12V, sufficient for 800g vehicle acceleration
- **Bearing System**: Two precision bearings minimizing rotational friction
- **Steering Load Management**: Mechanism optimized for servo torque characteristics
- **Impact Resistance**: Validated through comprehensive testing under competition conditions
  
### **Assembly Methodology**

</div>

<div align="center">
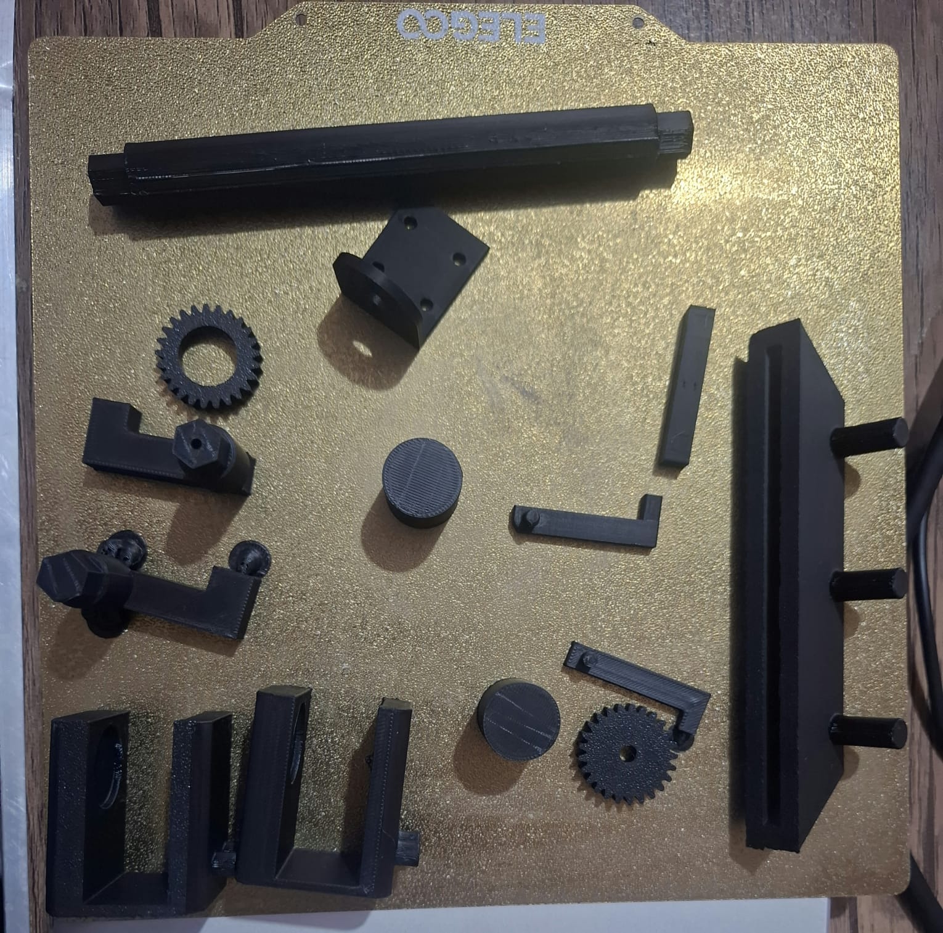
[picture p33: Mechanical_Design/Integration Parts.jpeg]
Assembly Process Documentation

</div>
<p align="center">
  <em>Staged assembly approach ensuring proper system integration and alignment</em>
</p>

**Assembly Sequence**:
1. **Drive System Integration**: Differential assembly and motor mounting with M3 hardware
2. **Steering Mechanism Installation**: Ackermann linkage and servo integration
3. **Wheel System Assembly**: Bearing installation and wheel mounting
4. **Electronic System Integration**: Bread board installation and component connection
5. **Final System Validation**: Comprehensive functional testing and alignment verification

---

## 💻 **Software Architecture** 

Our software implementation employs a distributed processing architecture that optimizes performance through specialized task allocation between multiple processors.

### **System Architecture Overview**

<table>
<tr>
<td width="60%">

**Processing Distribution**:
- **Vision Processing Unit**: Raspberry Pi 4 handling real-time image analysis and high-level decision making
- **Sensor Fusion Unit**: esp32 managing multi-sensor data acquisition and preprocessing
- **Communication Bridge**: Bidirectional UART protocol at 115200 baud for inter-processor data exchange

**Core Software Components**:
- [`vision_source.py`](src/open.py) - Open challenge navigation algorithms and obstacle challenge with integrated parking
- [`calibration.py`](src/obstacle.py) - calibration for the different variables  
- [`esp32_car.ino`](src/uart_slave.ino) - Sensor and motor management firmware

</td>
<td width="40%">
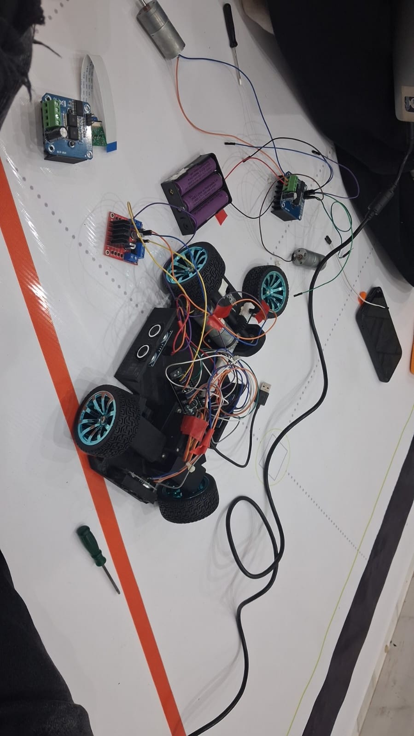
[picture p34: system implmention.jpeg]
System Implementation

<p align="center"><em>Integrated development and testing setup</em></p>
</td>
</tr>
</table>

### 📄 **Development Environment & Code Deployment**

#### **Raspberry Pi 4 Model B (Camera Microcontroller)**
- **Programming Language**: Python 3 for rapid development and testing
- **Development Interface**: Direct micro USB / HDMI connection to Raspberry Pi with a live OpenCV debug window (`cv.imshow`)
- **Core Libraries**:
  - `opencv-python (cv2)` - Image preprocessing, HSV color masking, and contour-based object detection
  - `numpy` - Array operations for HSV bounds and morphological kernels
  - `pyserial` - UART serial communication with the ESP32 microcontroller

#### **esp32 (Sensor and Motor Microcontroller)**
- **Programming Language**: Arduino C++ for efficient sensor and motor data handling
- **Development Interface**: Standard micro USB connection to evaluation board
- **Essential Libraries**:
  - `ESP32Servo.h` - PWM-based control of the steering servo
- **Communication Protocol**: UART Serial (115200 baud) between the Raspberry Pi and ESP32, used to relay vision-based obstacle data (color, distance, position)

#### **Development Workflow Optimization**
We implemented magnetic USB connectors for the camera microcontroller, providing significant advantages during intensive development cycles. The magnetic interface enables rapid connection changes, prevents physical port damage from repeated use, and streamlines the programming and debugging process.

#### **Code Deployment Process**

1. **Raspberry Pi 4 Model B Python Deployment**:
   - Transfer `.py` source files directly to microcontroller filesystem using magnetic USB connection
   - Automatic execution initialization from `vision_source.py` on system startup
   - Adding the calibration code in order to adjust the variables
   - No compilation overhead - immediate interpreted execution for rapid iteration

2. **esp32 Arduino Deployment**:
   - Compile source code in Arduino IDE with ESP32 board package support
   - Upload compiled binary via micro USB interface to evaluation board
   - Precompiled firmware deployment ensuring reliable sensor and motor operation

### 🎨 **Vision Processing Strategy**
We selected the **HSV color space** for its superior performance under variable lighting conditions compared to traditional RGB representation. Detection thresholds for the red and green obstacle pillars, as well as the white track floor, were manually calibrated and fine-tuned per venue using a dedicated debug mask window.

**Technical Rationale**: HSV colorspace provides adequate performance for our application requirements, isolating hue independently from brightness/lighting variance, while more complex approaches (e.g. machine learning-based detection) would introduce unnecessary computational overhead without significant benefits for this specific use case.

**Calibration Debug Windows**:

## 📸 **Testing & Calibration Visuals**

<div align="center">
  
### **Detection Code Testing**
Testing The Detection Code

### **Calibration Testing**
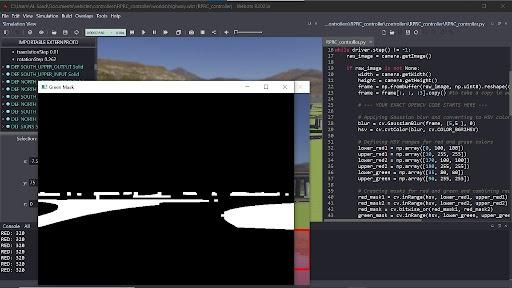
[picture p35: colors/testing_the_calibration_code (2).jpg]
Testing The Calibration Code


</div>

### 🧭 **Navigation Algorithm Implementation**

#### **Obstacle Challenge Navigation**

**State Machine Flow**:

Vision Obstacle Avoidance → Clearance → Corner Turn → Wall Following (repeat)
↑ ↑ ↑ ↑
Camera Color Post-Obstacle Ultrasonic Ultrasonic
Detection (R/G) Stabilizing Front Distance Left/Right PID

**Navigation Pseudocode**:

INITIALIZE sensors, center steering, stop motor

LOOP:
READ ultrasonic distances (front, left, right)
READ vision data from camera (color, distance, x-position)

IF obstacle color == RED and distance within range:
    STEER hard RIGHT, drive at obstacle speed
    CONTINUE to next loop

IF obstacle color == GREEN and distance within range:
    STEER hard LEFT, drive at obstacle speed
    CONTINUE to next loop

IF recently cleared an obstacle (within clearance window):
    CENTER steering, drive at clearance speed
    CONTINUE to next loop

IF currently turning a corner:
    CONTINUE steering toward corner direction
    IF front distance becomes clear OR max corner time exceeded:
        END corner, center steering
    CONTINUE to next loop

IF front distance

**Color-Specific Behaviors**:
- **Red Object Detection**: Right-side bias navigation with maintained offset
- **Green Object Detection**: Left-side bias navigation with maintained offset  
- **Position Maintenance**: Consistent pixel positioning for smooth obstacle tracking

## 📸 **Testing & Calibration Visuals**

<div align="center">
  
### **Red Color Detection**
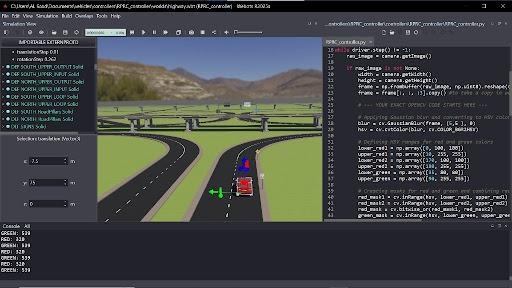
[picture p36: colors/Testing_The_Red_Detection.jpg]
Testing The Red Detection


</div>

### **Sensor and motor Fusion Implementation**

**Data Integration Pipeline**:
```
esp32 Sensors ←→  UART  ←→ Raspberry Pi 4 Model B → Sensor Fusion → Control Decisions
     ↑                            ↑                   ↑               ↓
  Ultrasonic Left               Camera           PID Controller   Motor/Servo
  Ultrasonic Right              Vision           State Machine     Actuators
  Ultrasonic Front                                                                                                    
   Encoder Data               
                               
```

### **Control System Implementation**

**Steering Control Algorithm**:
```python
# Proportional controller implementation for smooth navigation
def calculate_steering_correction(target_cx, frame_center_x):
    error = target_cx - frame_center_x
    steering_angle = error * KP_GAIN
    steering_angle = clamp(steering_angle, -0.5, 0.5)
    return steering_angle
```

### **Inter-Processor Communication**

**UART Protocol Specification**:
- **Baud Rate**: 115200 for reliable data throughput
- **Command Structure**: Comma-separated plain-text messages terminated by newline
- **Data Validation**: Field-count check (color, distance, x-position) before parsing
- **Error Recovery**: Timeout-based fallback - if no valid message is received within the timeout window, the obstacle state automatically resets to "none detected"

**Master (Raspberry Pi 4) → Slave (ESP32) Messages**:
- `R,<distance>,<x_position>` - Red obstacle detected: distance in cm, horizontal pixel position
- `G,<distance>,<x_position>` - Green obstacle detected: distance in cm, horizontal pixel position
- `N` - No obstacle currently detected
**Slave Response Formats**:
- **All sensors**: `left_distance,right_distance,encoder_distance\n`
- **Left Ultrasonic only**: `left_distance\n`
- **Right Ultrasonic only**: `right_distance\n`
- **Encoder only**: `encoder_distance\n`

### **Parking Maneuver Analysis**

Our compact dimensions required innovative parking strategies to operate within the constrained parking space.

### **Parallel Parking Strategy Optimization**

**🚧 Challenge**: Our compact vehicle length required extremely precise maneuvers.

- **Critical Clearance Design**: Narrow extension width allowed wall clearance during turns
- **🔄 Maneuverability Enhancement**: Additional space enabled reliable parking execution
**Multi-Stage Parking Sequence**:
1. **Approach Phase**: Follow magenta wall using camera guidance
2. **Turn-in Execution**: 80-degree turn outside parking spot
3. **Alignment Phase**: Odometry-based reverse positioning
4. **Reverse Maneuver**: Controlled backing for final alignment
5. **Straighten Phase**: Final orientation adjustment

### Parallel Parking – Potential Improvements
- Pure vision-based parking using parking walls as obstacles → eliminates Ultrassonic distance dependency and works even if the parking zone is shifted elsewhere.
- Single-motion slow parking trajectory instead of safer fast three-segment → would save ~1.5 s .

### **Obstacle Navigation Patterns**

The algorithm handles all possible obstacle combinations through systematic pattern recognition and response.

<div align="center">
Clockwise Navigation Patterns
Counter-clockwise Navigation Patterns
</div>
<p align="center">
  <em>Comprehensive obstacle combination analysis for both navigation directions</em>
</p>

### **Vision Processing Pipeline**

1. **Image Capture**: 320×240 resolution at 26 frames per second
2. **Color Transformation**: RGB to LAB colorspace conversion
3. **Feature Detection**: Blob analysis with size and shape filtering
4. **Target Identification**: Largest valid blob selection for reliability
5. **Error Calculation**: Position deviation from desired tracking point

<div align="center">
Single Color Detection
<br><br>
Red Color Detection
</div>

### **Software & Algorithms – Potential Improvements**
- Replace hand-tuned proportional-only steering with a full PID controller → would reduce oscillation and improve response to sudden error changes, especially during obstacle avoidance.
- Add IMU-based heading correction (e.g. MPU6050 on the ESP32) as a backup when ultrasonic wall readings are lost or unreliable, instead of relying on ultrasonic distance alone for cornering.
- Auto-calibrate HSV thresholds at startup using a reference color card, reducing the need for manual venue-specific tuning of the lane/red/green masks.
- Enable bidirectional UART communication → let the ESP32 report back sensor data (front/left/right distances) to the Raspberry Pi, allowing more informed vision-based decisions instead of one-way commands.

Complete software implementation details available in our [source code documentation](software/README.md).

---

## 📹 **Performance Videos** 

Our development process included precise testing and validation to ensure competition-ready performance across both challenge scenarios.

### **Competition Performance**

- **Open Challenge**: 16-second perfect score demonstration
- **Obstacle Challenge**: 35-second perfect score with integrated parking
- **Detection Reliability**: >95% accuracy across variable lighting conditions
- **System Responsiveness**: <50ms latency from detection to actuation

### **Video Documentation**

Complete performance demonstrations showcasing our vehicle's capabilities:

**Media Production**: All logos and visual media edits were created by our team using the ***ibisPaint X*** mobile application. Video overlay commentary and caption explanation edits were also done by our team using ***CapCut*** for professional presentation of our performance videos.

---

## 🌐 **GitHub Utilization & Development** 

GitHub served as the central platform for project management, version control, and public documentation. To ensure a well-organized and professional repository, we followed a milestone-based development workflow. Development and testing were conducted locally, with updates committed and documented after the completion of major engineering milestones, such as chassis finalization, sensor integration, and deployment of the core algorithms. This approach maintained a clear, structured, and easily traceable project history for both the development team and the wider community.

### **Development Workflow Strategy**

**Structured Development Approach**:
- **Local Development Environment**: Focused development work carried out on local machines using feature branches
- **Milestone-Based Committing**: Deliberate commits made at key points marking meaningful technical progress
- **Quality Assurance**: Careful testing and documentation completed before pushing updates to the public repository
- **Clean Public History**: A well-organized repository that reflects a polished and professional development journey

**File Sharing and Public Updates**: To keep our work accessible and easy for others to reproduce, all project assets — including CAD files (`models/`), electrical schematics (`schemes/`), and source code (`src/`) — are published publicly at every major milestone. Prior to each release, we carefully organize and clean up our code, data, and documentation to maintain a structured, easy-to-navigate repository. To support full transparency and proper version tracking, the exact date and time of each update is clearly noted in our README files.

### **Commit History & Project Evolution**

Our development timeline from June  to september 2026 demonstrates consistent progress and systematic engineering:

**Key Development Milestones**:
- **July 2026**: Core mechanical design and electronic system implementation
- **August 2026**: Repository initialization and project structure establishment  
- **August 2026**: national competition preparation and system optimization

**Commit Philosophy**: Each of our 20+ commits represents substantial technical progress, including:
- Complete mechanical system implementations (`design_base.3mf`, `4_gear_differential.3mf`)
- Electronic schematic and wiring documentation (`wiring_diagram.jpg`)
- Software algorithm development and optimization (`open.py`, `obstacle.py`)
- Comprehensive technical documentation updates across all 8 specialized folders
- Performance validation and testing results with competition videos

### **Repository Organization Excellence**

**Comprehensive Documentation Structure**:
- **8 Specialized Folders**: Each containing detailed technical README documentation
- **Structured File Organization**: Logical grouping of related technical assets
- **Professional Presentation**: Clean, well-organized repository layout
- **Easy Navigation**: Intuitive structure for both technical judges and future developers

### **Supporting Future Development & Replication**

<div align="center">

## 🔧 **EASY REPLICATION & FUTURE DEVELOPMENT**

### **Our documentation enables effortless duplication by other teams and developers**

</div>

**Replication-Focused Design**:
- **Complete Bill of Materials**: All components clearly specified with datasheet information
- **Step-by-Step Assembly Guides**: Detailed instructions for mechanical and electronic assembly
- **Manufacturing Files**: 3MF format for universal 3D printing compatibility
- **Source Code Availability**: Complete software implementation with detailed comments and explanations
- **Troubleshooting Guidance**: Solutions to common implementation challenges

**Supporting Others and Future Development**: We're happy to see others learn from what we've built, which is exactly why we chose the AGPL-3.0 license — it deliberately prevents our work from being folded into closed-source or private projects. Thanks to this strong copyleft protection, anything built on top of our code, hardware, or mechanical design has to stay open and available to everyone. Researchers, students, and other teams are welcome to copy, adapt, and expand on what we've done for learning, research, or competition use. Since our codebase is kept simple and clearly documented, teams without deep computer vision experience should still be able to adjust it for a new venue or challenge without much difficulty. We'd also genuinely welcome outside contributions — whether that's a better control algorithm or support for new sensors — through pull requests or issues on GitHub.
**Future Development Pathways**:
- **Modular Architecture**: Easy component upgrades and system modifications using our socket-based design
- **Comprehensive Documentation**: Every design decision and implementation detail documented
- **Open Source Philosophy**: AGPL-3.0 license ensuring continued community access
- **Educational Focus**: Detailed explanations of engineering principles and design choices

### **GitHub Best Practices Implementation**

**Professional Repository Management**:
- **Regular Updates**: Consistent documentation improvements and technical refinements
- **Quality Standards**: High-quality images, professional diagrams, and clear technical writing
- **Accessibility**: Well-structured content suitable for both technical and non-technical audiences
- **Completeness**: Every aspect of the project thoroughly documented and accessible

**Documentation Excellence Standards**:
- ✅ **Complete Information**: Comprehensive coverage of all technical aspects across 8 specialized folders
- ✅ **Structured Organization**: Logical, easy-to-navigate repository structure with clear documentation hierarchy
- ✅ **Regular Commits**: Meaningful, milestone-based version control demonstrating systematic development
- ✅ **Enhanced Engineering Understanding**: Detailed design rationale and implementation insights exceeding basic requirements

---

## 📜 **License & Replication** 

### **Open Source Philosophy for Community Advancement**

**Replication-Focused Documentation**:
- **Complete Technical Transparency**: Every design decision and implementation detail documented
- **Manufacturing Accessibility**: Use of widely available components and custom manufacturing methods
- **Educational Value**: Detailed explanations enabling understanding of engineering principles
- **Future Development**: Clear pathways for system improvements and modifications

This project is licensed under the **GNU Affero General Public License v3.0 (AGPL-3.0)** to promote open collaboration, ensure continued community access to derivative works, facilitate easy replication by future developers and competition teams, and foster ongoing innovation through publicly accessible developments.

```
GNU Affero General Public License v3.0

This program is free software: you can redistribute it and/or modify
it under the terms of the GNU Affero General Public License as published
by the Free Software Foundation, either version 3 of the License, or
(at your option) any later version.

This program is distributed in the hope that it will be useful,
but WITHOUT ANY WARRANTY; without even the implied warranty of
MERCHANTABILITY or FITNESS FOR A PARTICULAR PURPOSE. See the
GNU Affero General Public License for more details.

You should have received a copy of the GNU Affero General Public License
along with this program. If not, see <https://www.gnu.org/licenses/>.
```

### **Comprehensive Documentation Access**

<div align="center">

## 📚 **DETAILED TECHNICAL DOCUMENTATION**

### **Explore our specialized documentation for complete technical details**

</div>

- **For mechanical design and 3D models**: * [Models Documentation](Mechanical_Design/README.md)  
- **For electrical schematics and wiring**: [Schemes Documentation](schemes/README.md)  
- **For software implementation and algorithms**: [Software Documentation](software/README.md)  
- **For competition performance videos**: [Video Documentation](Videos/README.md)  
- **For additional resources and photos**: [Other Documentation](Others/README.md)
- **For team information**: [Team Photos Documentation](Team_Photos/README.md)
- **For vehicle documentation**: [Car Photos Documentation](Car_Photos/README.md)

---

<div align="center">

## 🎯 **Prepared for national Competition Excellence**

**Team RPRC - *Never Stop Developing Unless We Stop Learning***

### **Comprehensive documentation enabling easy replication and future development**



</div>

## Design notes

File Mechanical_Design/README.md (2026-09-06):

# Models Documentation

This folder contains the complete 3D CAD models and manufacturing files for Team RCBC's WRO 2026 Future Engineers robot. All mechanical components were custom-designed and manufactured in-house to achieve our goal. 

## 🎯 Mechanical Design Philosophy

<p align="center">
  CAD Isometric View
</p>

<p align="center">
  <em>Direct comparison: 1) CAD design visualization</em>
</p>

## ⚙️ Core Mechanical Systems

### 🔄 Custom Ackermann Steering Geometry
The steering system implements true Ackermann principles where each wheel points toward a common center point during turns, minimizing tire scrub and maximizing stability.

<p align="center">
  <table align="center">
    <tr>
      <td align="center">
        Ackermann Steering Simulation
      </td>
      <td align="center">
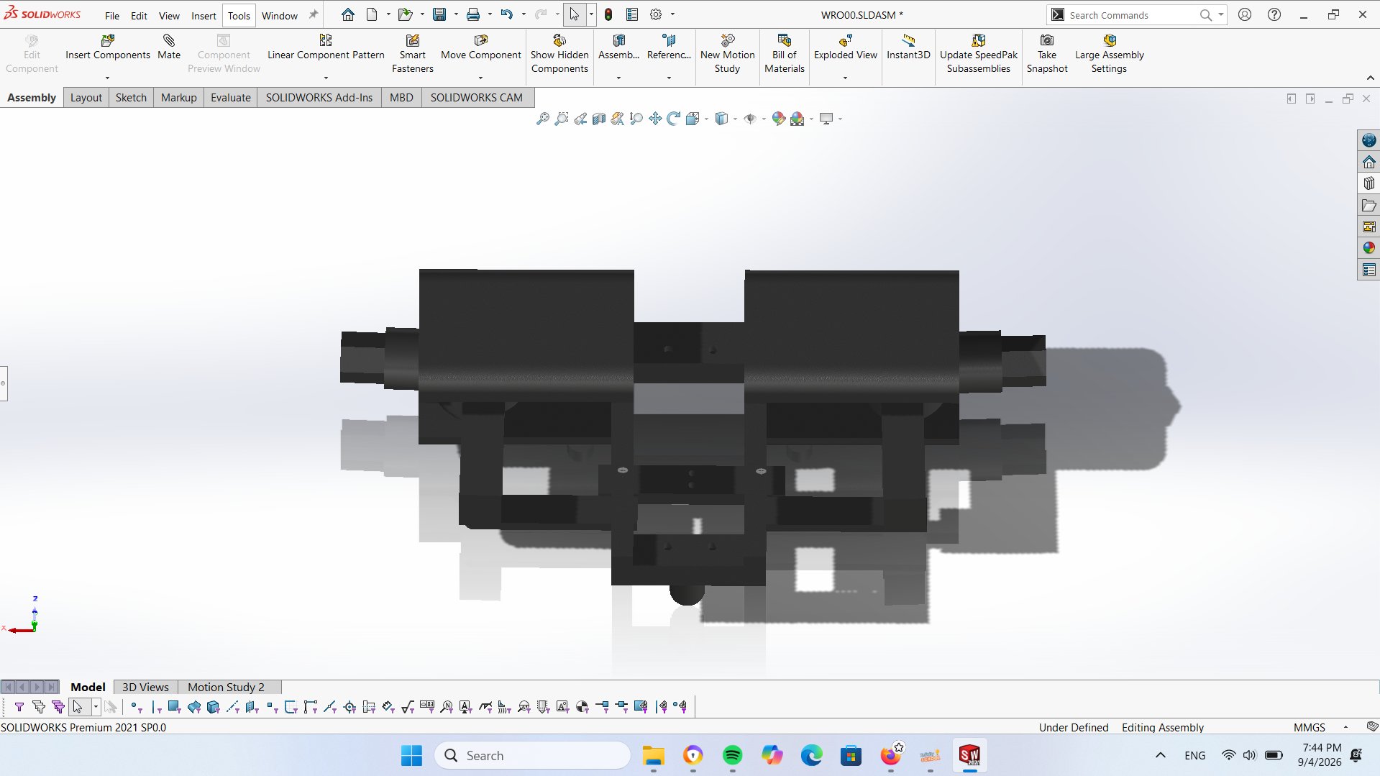
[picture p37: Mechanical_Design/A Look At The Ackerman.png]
Ackermann Geometry Calculations
        
      </td>
    </tr>
    <tr>
      <td align="center" colspan="2">
        Ackermann Mechanism View
      </td>
    </tr>
  </table>
</p>

<p align="center">
  <em>1) Real-time CAD simulation demonstrating steering mechanism operation • 2) Engineering calculations showing Ackermann geometry and optimal turning radius</em><br>
  <em>Higher quality video: <a href="../video/3d_CAD_motion.mp4">3d_CAD_motion.mp4</a></em>
</p>
**Engineering Progress & Refinement:**
- **Initial Approach**: Print-in-place Ackermann steering with integrated moving parts
- **Performance Finding**: Initial excellent tolerance degraded after extensive testing causing wheel wiggle
- **Final Solution**: Multi-component steering with 3 M2 screws and 3 M2 lock nuts ensuring permanent precision
- **True Ackermann Geometry**: Each wheel points toward common center point during turns for minimal tire scrub

### 🔧 4-Gear Mechanical Differential
Our custom differential ensures smooth power distribution to both rear wheels during turns, preventing wheel slip and maintaining traction during complex maneuvers.

<p align="center">
  <table align="center">
    <tr>
      <td align="center">
        Physical Differential Test
      </td>
      <td align="center">
        CAD Differential View 1<br>
        CAD Differential View 2
      </td>
    </tr>
  </table>
</p>

<p align="center">
  <em>1) Physical differential test demonstrating independent wheel rotation • 2) CAD views showing 2-gear differential assembly from multiple angles</em><br>
  <em>Higher quality video: <a href="../video/differential_test.mp4">differential_test.mp4</a></em>
</p>

**Gear System Specifications:**
- **Spur Gear Reduction**: 25-tooth and 25-tooth providing optimized 1:1 ratio
- **Precision Manufacturing**: 100% infill for maximum strength and durability
- **Efficiency Optimization**: Minimal power loss through precisely calculated gear meshing

### 🏗️ Chassis and Structural Design
The main chassis integrates all mechanical and electronic systems while maintaining structural integrity and achieving minimal weight through strategic design.

<p align="center">
  <table align="center">
    <tr>
      <td align="center">
        Chassis Development
      </td>
      <td align="center">
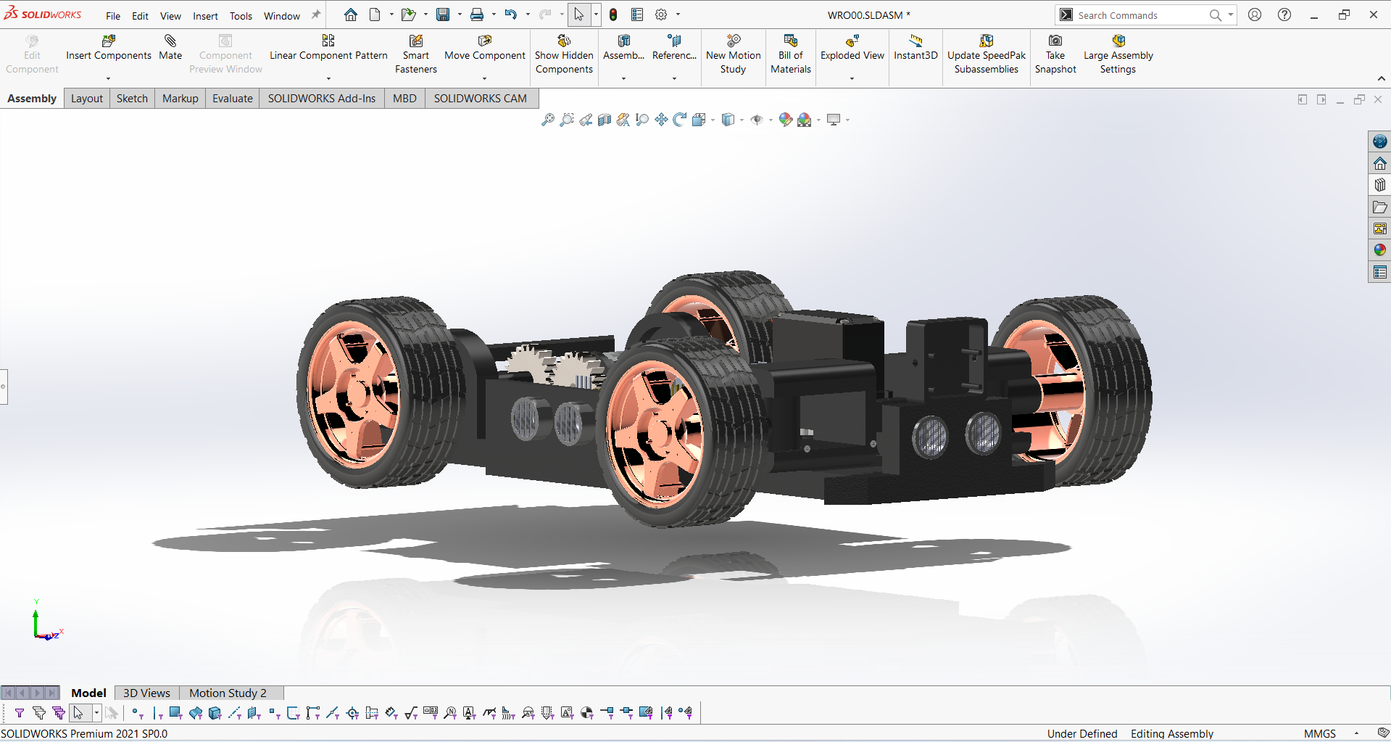
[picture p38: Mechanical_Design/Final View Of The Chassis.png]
CAD base View 1
        <br>
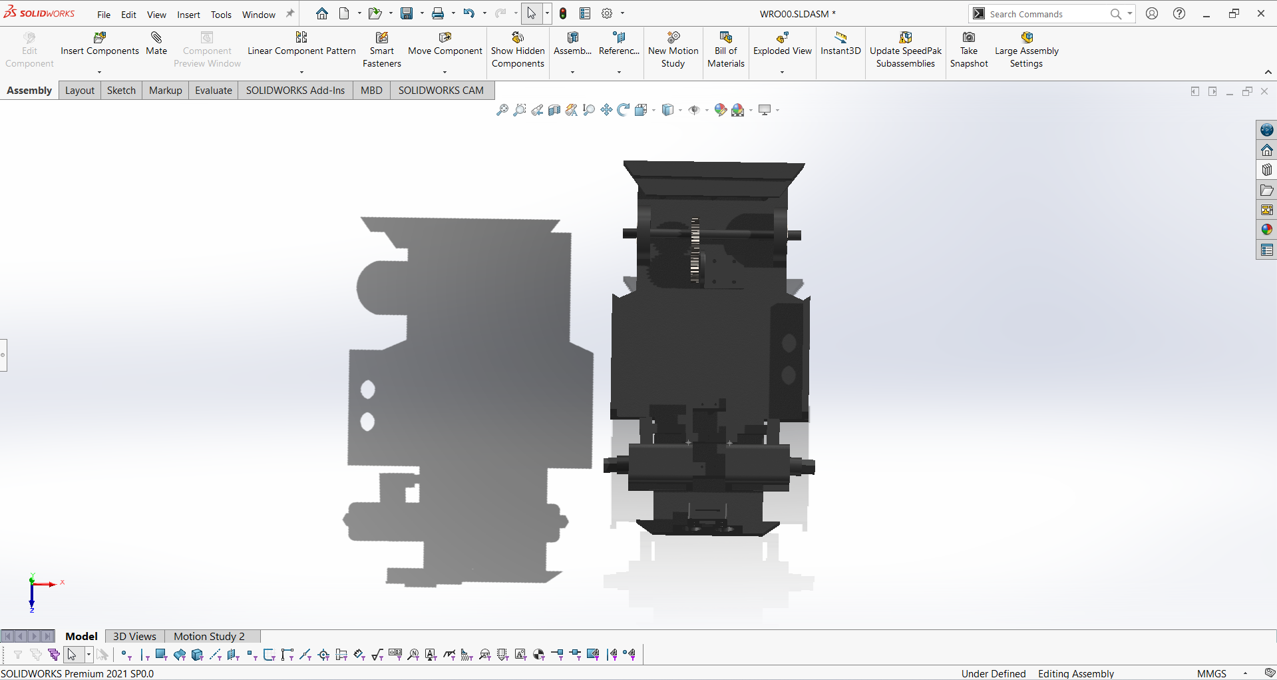
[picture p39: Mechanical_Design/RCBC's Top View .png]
CAD base View 2
        
      </td>
    </tr>
  </table>
</p>
<p align="center">
  <em>1) Extensive chassis design evolution through multiple iterations • 2) CAD views showing main chassis structure from different perspectives</em>
</p>

**Structural Engineering Elements:**
- **Integrated Component Mounting System**: Precision slots and holders for Electronics, servo, motor, and battery
- **Optimized Weight Distribution**: Strategic mass placement ensuring stable navigation and quick response
- **Bearing Integration**: two precision bearings (one per wheel) for smooth rotation with minimal friction
- **Access and Maintenance Design**: Strategic openings enabling easy component replacement and field adjustments

## 🏭 Manufacturing Process & Engineering Solutions

### 🖨️ 3D Printing Equipment & Material Strategy
We conducted extensive testing across multiple printing technologies on The internet and the market to achieve optimal results.

**CAD & Slicing Software Integration**:
- **Design Platform**: ***SolidWorks*** for comprehensive 3D modeling, simulation, and engineering analysis
- **Slicing Software**: ***UltiMaker Cura*** for optimized print preparation and manufacturing parameter management
- **Workflow Integration**: Seamless transition from CAD design to manufacturing-ready 3MF files

**Printing Equipment Evaluation:**
| Printer | Technology | Primary Usage | Materials Tested | Key Findings |
|---|---|---|---|---|
| **Ender 3v3** | FDM (Fused Deposition Modeling) | Final production | Hyper ABS, ABS+ | **Optimal Choice** - Reliable performance with ABS materials |
| **Zaxe Z3S** | FDM (Fused Deposition Modeling) | Development phase | PLA, ABS | Excellent precision and reliability |
| **Bambu Lab A1** | FDM (Fused Deposition Modeling) | Rapid prototyping | PLA | Exceptional speed for design iterations |
| **Markforged Mark Two** | CFR (Continuous Fiber Reinforcement) | Advanced testing | Onyx (Nylon+CF) | Limited by proprietary Eiger software constraints |
| **Formlabs Form 3B+/3+** | SLA (Stereolithography) | Detail testing | SLA Resins | Superior detail but insufficient impact strength and resin alternatives|

### 🛠️ Comprehensive Material Selection Process
**Final Material: PLA+ from Patreon**  
Selected for superior layer adhesion, impact resistance, and thermal stability required for competition conditions.

**Material Testing Results & Rationale:**
- ✅ **FDM - PLA+ (Production Choice)**: Optimal strength-to-weight ratio, excellent layer bonding, competition-ready durability
- ✅ **FDM - Hyper ABS (Development Phase)**: Good performance used during national tournament
- ❌ **FDM - ABS+**: Adequate for initial prototyping but insufficient impact resistance for competition use
- ❌ **FDM - PETG**: Challenging dimensional accuracy and stringing issues affecting gear performance
- ❌ **SLA - Resin**: Exceptional detail resolution but too brittle for structural components under stress, plus limited availability for reproduction

**Selection Philosophy**: Chosen materials prioritize **accessibility** and **reproducibility** alongside performance, ensuring other teams can easily replicate our design using commonly available FDM technology rather than specialized industrial equipment.

**Technology Overview:**
- **FDM (Fused Deposition Modeling)**: Material extrusion through heated nozzle, ideal for functional parts
- **SLA (Stereolithography)**: UV laser curing liquid resin, excellent for high-detail prototypes  
- **CFR (Continuous Fiber Reinforcement)**: Composite printing with continuous fiber strands for maximum strength

### 🔥 Engineering Challenge: ABS Printing Without Dedicated Enclosure
**Problem Identification**: Printing ABS material on Ender 3v3 without dedicated heated enclosure caused warping and layer separation issues.

**Innovative Solution**: Developed room-scale thermal management system using the entire workspace as a controlled environment.

**Thermal Management Process:**
1. **Environmental Pre-conditioning**: Maintain ambient temperature at 28-32°C throughout printing process
2. **Stable Printing Execution**: Complete ABS printing with consistent thermal environment minimizing thermal gradients
3. **Controlled Gradual Cooling**: Allow natural cooling with minimal ventilation to prevent rapid temperature changes
4. **Stabilized Part Extraction**: Remove finished components only after complete thermal stabilization
5. **Process Repeatability**: Continue manufacturing sequence using identical thermal management for consistency

**Optimized Printing Parameters:**
- **Layer Resolution**: 0.08mm–0.1mm for dimensional accuracy and surface finish
- **Infill Strategy**: 30-40% for structural chassis components, 100% for gears and high-stress elements
- **Temperature Control**: Nozzle 250-260°C, Bed 80-85°C for optimal layer adhesion
- **Nozzle Configuration**: 0.4mm standard nozzle (available equipment)
- **Support Strategy**: Tree supports preferred for optimal material usage and clean removal

**Advanced Speed Settings:**
- **Print Speeds**: Outer wall 200 mm/s, Inner walls 300 mm/s, Sparse infill 200 mm/s
- **Specialized Settings**: Top surface 200 mm/s, Gap infill 200 mm/s, Support 150 mm/s
- **Quality Optimization**: Support interface 80 mm/s, First layer 60 mm/s
- **Travel & Overhangs**: Travel speed 500 mm/s, Overhang reduction 30-20-10%
- **Bridge Control**: External bridges 25 mm/s, Internal bridges 160 mm/s

### 📁 3amf File Format Advantage
**Why 3amf for Maximum Reproducibility:**
- **Universal Compatibility**: Works across all printer brands and slicing software, unlike machine-specific G-code
- **Complete Scene Preservation**: All print settings, orientations, and arrangements embedded
- **Advanced Feature Support**: Custom support placements, support settings, and manual modifications preserved
- **Color & Material Information**: Visual specifications maintained for consistent results
- **Exact Alignment**: Bed positioning and part orientation preserved for identical outcomes
- **One-Click Manufacturing**: Direct import with all manufacturing parameters intact for perfect reproduction

## 🧩 Comprehensive Assembly Guide

### 📋 Detailed Step-by-Step Assembly Process

<p align="center">
  Assembly Process
</p>
<p align="center">
  <em>Intermediate assembly stage showing mechanical systems integration and component relationships</em>
</p>

**Phase 1: Drive Train Assembly & Power Transmission**
1. **Differential System Installation**: Precision alignment of 4-gear mechanism ensuring smooth power transfer
2. **Motor Integration**: Secure mounting of 450 RPM JGA270-370 motor with custom enclosure using M2 hardware
3. **Gear Meshing Verification**: Ensure proper engagement of 25T and 26T spur gears with optimal backlash

**Phase 2: Steering System Integration & Control**
1. **Ackermann Mechanism Assembly**: Install steering arms and linkage with 4 M2 screws and 2 M2 lock nuts
2. **Servo Integration**: Connect Feetech Mg966R servo to steering mechanism with precise alignment
3. **Back Wheel System**: Install bearings and Back rims ensuring smooth rotation and minimal play

**Phase 3: Chassis Completion & System Integration**
1. **Electronic Platform Mounting**: Secure Bread boards with all electronic systems in designated slots
2. **Power System Installation**: Mount LiPo battery in optimized weight distribution position
3. **Final Mechanical Validation**: Comprehensive check of all systems for optimal performance and reliability

## 🔄 Component Development & Engineering Iteration

<p align="center">
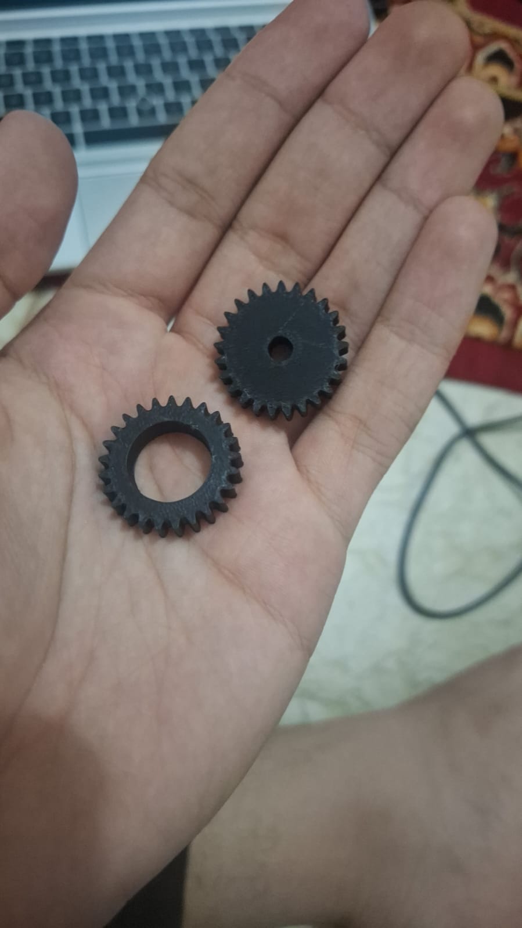
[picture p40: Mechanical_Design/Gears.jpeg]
Component Development
  
</p>
<p align="center">
  <em>Comprehensive component evolution demonstrating our iterative design process across gear systems, steering mechanisms, and structural elements</em>
</p>

**Development Scope & Engineering Iterations:**
- **Gear System Evolution**: Multiple generations optimizing tooth profile, meshing efficiency, and strength
- **Steering Mechanism Refinement**: Various iterations achieving precision control with minimal mechanical play
- **Structural Component Optimization**: Chassis, rims, and mounting systems refined through performance testing
- **Integration Validation**: Continuous testing ensuring component compatibility and system reliability
- **Print-in-Place Validation**: Manufacturing process refinement for optimal production quality

## 🎯 Advanced Wheel & Tire System Engineering

### 🔍 Comprehensive Tire Analysis & Performance-Based Selection

<p align="center">
  <table align="center">
    <tr>
      <td align="center" width="40%">
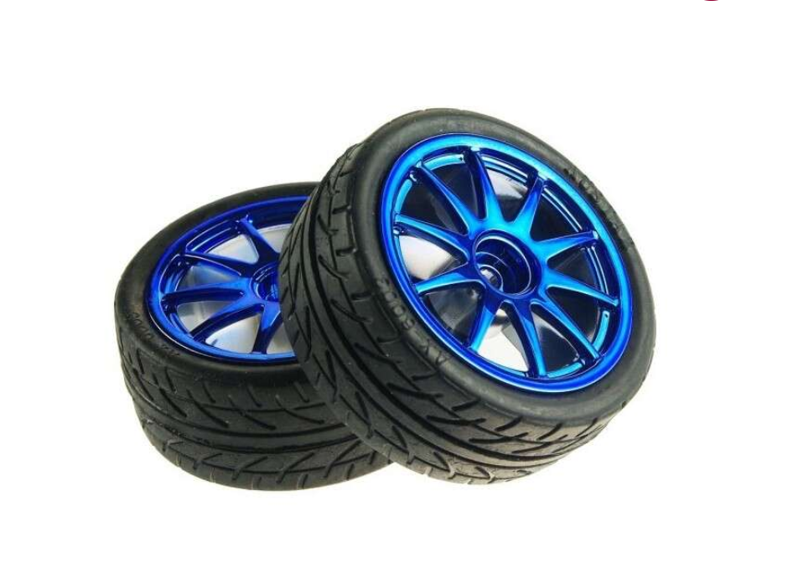
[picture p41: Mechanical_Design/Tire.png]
RC On-Road Tire Specifications
        
      </td>
      <td align="left" width="60%">
        <h4>🏎️ Why On-Road Performance Tires?</h4>
        <ul>
          <li><strong>Low-Profile Tread:</strong> Designed for high-speed stability and maximum traction on smooth surfaces.</li>
          <li><strong>Aluminium Rim Structure:</strong> Provides zero flex under high torque compared to flexible plastic wheels.</li>
          <li><strong>Standard Hex Hub:</strong> Ensures precise power transfer from motors without rotational slip.</li>
        </ul>
      </td>
    </tr>
  </table>
</p>

**Technical Tire Comparison & Engineering Analysis:**

| Engineering Aspect | Our Robotic Wheel TIre | Custom Silicone Tires |
|---|---|---|
| **Material Composition** | SEBS (Styrene-Ethylene-Butylene-Styrene) | Custom silicone compound formulation |
| **Theoretical Traction** | Good predictable performance | Higher theoretical coefficient |
| **Actual Performance** | Optimal for our weight class | Similar results despite theoretical advantage |
| **Design Compatibility** | Perfect fit with custom rims | Required significant rim redesign |
| **Manufacturing Consistency** | Excellent quality control | Variable performance between batches |
| **Weight Impact** | Minimal additional mass | Slightly increased rotational mass due to a larger inner rim with more filling, necessary for better stretching of the silicone tire |

**Final Engineering Selection: Robotic Wheel Tire**
- **Optimal Dimensions**: 65mm diameter × 28mm width fitting our size constraints
- **Key Design Feature**: Circumferential center ridge providing stability and predictable handling
- **Performance Characteristics**: Consistent traction with minimal rolling resistance
- **Reliability Assurance**: Proven durability under extended competition conditions

### 🎯 Performance Analysis: Why Theory Didn't Match Reality

<div align="center">
<table>
<tr>
<td><strong>🏋️ Weight Dynamics</strong><br>130g total weight changes traction physics</td>
<td><strong>⚡ Speed Factors</strong><br>1.4 m/s momentum dominates cornering</td>
</tr>
<tr>
<td><strong>🎯 Precision Engineering</strong><br>Near-zero mechanical play in systems</td>
<td><strong>📊 Test Results</strong><br>Identical lap times with both tires</td>
</tr>
</table>
</div>

**Ultra-Lightweight Physics Revolution:**
- **Mass Revolution**: At 800g, traditional tire traction models don't apply
- **Center of Gravity Mastery**: Extremely low CG reduces dependency on tire grip
- **Weight Distribution Science**: Strategic mass placement provides inherent stability

**High-Speed Momentum Dominance:**
- **Physics Reality**: At 1.5 m/s operational speed, momentum overpowers traction benefits
- **Cornering Truth**: Sharp turns rely on precise steering, not tire compound
- **Performance Data**: Both tires demonstrated identical competition performance

**Precision Engineering Advantage:**
- **Zero-Play Systems**: Our mechanical design eliminates steering and drive train slack
- **Predictable Response**: Vehicle handles identically regardless of tire material
- **Algorithm Optimization**: Navigation tuned for positional accuracy over traction dependence

**The Engineering Conclusion:**
While silicone promised higher friction coefficients, our ultra-lightweight, high-precision platform operating at speed revealed that traditional tire performance metrics become secondary. The combination of minimal mass, optimized dynamics, and precision control systems created a scenario where both options performed identically in real-world testing, making consistency and compatibility the deciding factors.

## 📊 Engineering Calculations & Performance Validation

**Motor & Drive Train Engineering Analysis:**
- **Motor Specification**: 450 RPM N20 DC motor with integrated Hall effect magnetic quadrature encoder
- **Gear Reduction System**: 1:1 ratio through custom spur gear design providing optimal torque-speed balance
- **Wheel RPM Calculation**: 450 RPM derived through:
    - Wheel RPM = Motor RPM × Gear Ratio = 450 × (1/1) = 450 RPM
- **Theoretical Maximum Speed**: 1.53 m/s calculated through:
    - Wheel radius = 65mm / 2 = 32.5mm = 0.0325m
    - Speed = (2 × π × wheel radius) × (Wheel RPM / 60)
    - Speed = (2 × π × 0.0325) × (450 / 60) ≈ 1.53 m/s
- **Operational Speed Selection**: 1.4 m/s via PWM control providing optimal stability and control response
- **Speed Optimization**: Based on comprehensive calculations comparing wheel/tire sizes and motor speeds for the 3m × 3m game field. Development comparisons available at
- <p align="center">
  <table align="center">
    <tr>
      <td align="left">
        <h4>⚡ Speed Calculations (450 RPM Motor & 1:1 Gear Ratio)</h4>
        <p><strong>Formula:</strong> <code>v = (π × d / 100) × (RPM / 60)</code></p>
        <ul>
          <li><strong>Motor Base Speed:</strong> 450 RPM</li>
          <li><strong>Gear Ratio:</strong> 1:1 → <strong>Wheel Speed:</strong> 450 RPM</li>
          <li><strong>Wheel Diameter:</strong> 65 mm (6.5 cm)</li>
          <li><strong>Theoretical Speed:</strong> <strong>1.53 m/s</strong></li>
        </ul>
      </td>
    </tr>
  </table>
</p>

**Structural & Performance Engineering Validation:**
- **Motor Torque Analysis**: ~1.25 Nm at 12V providing sufficient force for 800g vehicle mass and acceleration requirements
- **Bearing System Design**: Optimized for minimal friction, long-term reliability, and precise wheel alignment
- **Steering Load Calculations**: Ackermann mechanism perfectly matched to servo torque capabilities and response requirements
- **Impact Resistance Validation**: Comprehensive testing under competition conditions confirming structural integrity

## 📁 Complete Manufacturing File Repository

### 🎯 Comprehensive 3D Printing Files & Assembly Specifications
*All files provided in **3MF format** for maximum reproducibility across different printers and slicers.*<br>
*Quantities listed are for one complete vehicle assembly*

| Component | File | Quantity | CAD Preview | Description |
|---|---|---|---|---|
| **Main Chassis** | [`RCBC Chassis.3MF`](RCBC%20Chassis.3MF) | 1 |  | Primary structure with integrated mounting system |
| **Motor Bracket** | [`JGA25-370 motor bracket.step.3MF`](JGA25-370%20motor%20bracket.step.3MF) | 1 |  | Mounting bracket specifically designed for JGA25-370 motor |
| **Ackerman Axle** | [`Ackerman Axle.3MF`](Ackerman%20Axle.3MF) | 1 |  | Main steering linkage for Ackermann geometry |
| **Knuckle Joint** | [`Knuckle_Joint_boze.3MF`](Knuckle_Joint_boze.3MF) | 2 |  | Steering knuckle joints for front wheels |
| **Rotation Left** | [`Rotation_Left.3MF`](Rotation_Left.3MF) | 1 |  | Left side steering rotation component |
| **Rotation Right**| [`Rotation_Right.3MF`](Rotation_Right.3MF) | 1 |  | Right side steering rotation component |
| **Servo Connector** | [`Servo_Connector.3MF`](Servo_Connector.3MF) | 1 |  | Linkage connecting the steering servo to the axle |
| **Spur Gear** | [`spur gear_am.3MF`](spur%20gear_am.3MF) | 1 |  | Main torque transmission spur gear |
| **Drive Shaft** | [`Shaft.3MF`](Shaft.3MF) | 1 |  | Main mechanical drive transmission shaft |
| **Camera Casing** | [`camera casing 1.3MF`](camera%20casing%201.3MF) | 1 |  | Enclosure and protection for the vision system |
| **Rear Spoiler** | [`spoiler.3MF`](spoiler.3MF) | 1 |  | Aerodynamic rear spoiler structure |

## 🚀 Engineering Design & Development Process

### 🔄 Comprehensive Iterative Engineering Approach

1. **Conceptual Design & Requirements Analysis**
   - Comprehensive size constraint analysis and optimization
   - True Ackermann steering geometry implementation and validation
   - Strategic component integration planning and spatial optimization

2. **Precision CAD Modeling & Engineering Simulation**
   - Detailed modeling in ***SolidWorks*** with manufacturing considerations
   - Motion simulation and validation for steering and drive train systems

3. **Prototyping & Performance Optimization**
   - Multiple iterations for mechanical tolerance refinement and optimization
   - Comprehensive material testing across various options and conditions
   - Print-in-place component validation and manufacturing process refinement

4. **Production Engineering & System Validation**
   - Optimized printing parameters implementation for production quality
   - Comprehensive assembly procedure development and documentation
   - Competition condition performance testing and validation

## ✅ Engineering Validation & Testing Protocols

### 🧪 Mechanical System Verification & Performance Testing

- **Differential Operation Validation**: Comprehensive testing of smooth torque distribution under various load conditions
- **Steering Geometry Confirmation**: Physical validation of true Ackermann principles in operational implementation
- **Structural Integrity Assessment**: Testing under various surface irregularities to confirm reliability, focusing on the effects of small bumps on a lightweight vehicle.
- **Bearing System Performance**: Long-term testing confirming smooth operation, minimal friction, and reliability

### 🏆 Competition Readiness & Reliability Engineering

- **Regulation Compliance Verification**: Comprehensive adherence to WRO vehicle specifications including 300x200mm maximum dimensions, 1.5kg maximum weight, 4-wheel design with one driving axle and one steering actuator
- **Operational Reliability Demonstration**: Extended testing showing consistent performance under competition pressure
- **Maintenance & Service Protocols**: Established procedures for competition-time adjustments and repairs
- **Backup System Preparation**: Redundant components and systems prepared for competition requirements

---

This comprehensive mechanical documentation provides complete transparency into our design process, manufacturing methods, validation procedures, and engineering decision-making. Every aspect of our mechanical system has been optimized for the unique challenges of autonomous navigation in the WRO 2026 Future Engineers category, enabling exact duplication while demonstrating engineering excellence through detailed component specifications, assembly instructions, performance data, and real-world validation.

For electrical systems documentation: [Schemes Documentation](../schemes/README.md)  
For software implementation and algorithms: [Software Documentation](../src/README.md)  
For performance demonstrations: [Video Documentation](../video/README.md)  
For additional resources and photos: [Other Documentation](../other/README.md)

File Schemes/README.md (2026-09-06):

[# ⚡ Schemes & Hardware Documentation

This folder contains the complete electrical schematics, wiring diagrams, power management documentation, and datasheet references for our WRO Future Engineers autonomous vehicle. The electrical system has been engineered to ensure optimal power distribution, minimal latency, and robust hardware integration.

---

## 🎯 Electrical Design Philosophy

Our system employs a modular dual-processing architecture to balance high-level computer vision with real-time hardware control:
* **High-Level Processing**: A **Raspberry Pi 4 Model B** handles camera feedback, lane detection, sign recognition, and path planning algorithms.
* **Low-Level Control & Sensor Fusion**: An **ESP32 (ESP-WROOM-32)** is dedicated to low-latency real-time task management, precision ultrasonic timing, and motor PWM drive output.

---

## 📋 Complete Bill of Materials (BOM)

| Component | Image | Datasheet Reference | Type | Primary Function |
|---|---|---|---|---|
| **Raspberry Pi 4 Model B** | Raspberry Pi 4 | `raspberry-pi-4-datasheet.pdf` | Single-Board Computer | Vision processing and high-level autonomous navigation |
| **ESP32 (ESP-WROOM-32)** | ESP32 | `ESP-WROOM-32.PDF` | Microcontroller | Real-time sensor reading, timing, and actuator drive logic |
| **Raspberry Pi Camera v2** | Camera Module | `RASPBERRY PI CAMERA V2 DATASHEET .PDF` | Vision Sensor | 8MP camera input for track boundary and sign detection |
| **HC-SR04** | *N/A* | `HC-SR04.PDF` | Distance Sensor | Ultrasonic range detection for obstacle avoidance |
| **DC Motor Driver** | *N/A* | `Motor Driver Data Sheet.pdf` | Motor Driver | H-bridge PWM control for drive motor speed/direction |
| **DC Motor** | DC Motor | `Motor_Data_Sheet.pdf` | Propulsion Actuator | Main drive propulsion motor |
| **Steering Servo (Mg966R)** | Mg966R Servo | *Standard Specs* | Steering Actuator | Ackermann steering mechanism control |
| **Buck Converters** | Buck Converter | *Standard Specs* | Power Management | Step-down voltage regulation (e.g., 12V to 5V) |
| **Batteries** | Batteries | *Standard Specs* | Power Source | Main vehicle power supply |

---

## 🔌 Complete Wiring System & Schematics

### Master Wiring Schematic & Physical Implementation

<p align="center">
  <a href="master_wiring_diagram.jpg" target="_blank">
    [PLACEHOLDER: Add master_wiring_diagram.jpg here]
  </a>
  [PLACEHOLDER: Add physical_board_layout.jpg here]
</p>
<p align="center">
  <em>1) Complete system wiring schematic showing all electrical connections • 2) Physical implementation of the electronics board</em>
</p>

### Component-Specific Schematics

<p align="center">
  [PLACEHOLDER: Add rpi_esp32_communication_scheme.jpg]
  [PLACEHOLDER: Add motor_driver_scheme.jpg]
</p>
<p align="center">
  <em>1) Raspberry Pi 4 to ESP32 UART/I2C Communication & Logic Level Wiring • 2) Motor Driver and DC Motor Control Scheme</em>
</p>

<p align="center">
  [PLACEHOLDER: Add sensors_wiring_scheme.jpg]
  [PLACEHOLDER: Add power_distribution_scheme.jpg]
</p>
<p align="center">
  <em>3) HC-SR04 Ultrasonic Sensors & Camera Wiring • 4) Power Step-Down and Battery Distribution Architecture</em>
</p>

---

## 🎮 Interface & Control Systems

<p align="center">
  [PLACEHOLDER: Start Button]
  [PLACEHOLDER: Logic Level Conversion]
</p>
<p align="center">
  <em>1) Tactile start button with direct connection to microcontroller • 2) Logic level converter implementation for signal safety</em>
</p>

**User Interface**:
- **Start Mechanism**: Tactile switch with direct pin-to-GND connection.
- **Visual Feedback**: Software includes LED visual feedback and hardware/software debounce logic.
- **Safety**: Momentary action design helps prevent accidental operation. The switch is active low, meaning it triggers the autonomous sequence when pressed, ensuring that operation only occurs during intentional activation.

**Signal Conditioning**:
- **Voltage Compatibility**: Logic level conversion ensures reliable 3.3V (ESP32/RPi) to 5V signal conversion for stable steering servo motor control.
- **Noise Immunity**: Proper decoupling capacitors and signal integrity maintenance prevent erratic servo jitters.
- **Control Signal Support**: Facilitates effective control of the actuators by ensuring proper voltage levels across the different logic domains.

### DC Motor Drive System
- **Motor Specification**: **JGA25-370** geared DC motor for robust propulsion.
- **Power Architecture**: The motor driver receives raw battery voltage directly to minimize power losses and maximize torque, isolating the motor current from the logic boards.
- **Logic Level**: Operates smoothly with 3.3V PWM control signals outputted by the ESP32.
- **Speed Calculation**: 
  - Base Motor RPM: 45rpm
  - Gear Ratio: 1:1
  - Wheel Diameter: 65mm
  - Theoretical Maximum Speed: 1.55 m/s
  - Operational Speed: Regulated via ESP32 PWM control for optimal turning stability and precise braking.

---

## 🛠️ Engineering Challenges & Solutions

### 1. Ultrasonic Sensor Beam Angle (Field of View) Challenge

**Problem Identification**:
- **Ground Intersection**: At medium ranges, the 15° acoustic beam angle cone of the HC-SR04 sensors intersects with the ground surface, causing false positive obstacle detections.
- **Robot Constraints**: The minimal height of our vehicle's chassis forces low sensor mounting, exacerbating the ground reflection issue.

**Engineering Solutions**:
1. **Angular Adjustment**: Sensors are mounted with a slight upward tilt (approx. 3-5 degrees) to increase the ground intersection distance beyond our braking threshold.
2. **Acoustic Dampening**: Using vibration-dampening mounts to prevent motor vibrations from causing mechanical echoes.
3. **Threshold Optimization (Software)**: The ESP32 utilizes a median filter and software distance thresholds to reliably detect real objects and ignore sudden ground interference spikes.

**Result**: Extended usable and clean detection range without compromising the low center of gravity of the vehicle.

### 2. Space & Board Optimization Strategy

To fit the dual-processor architecture and power management systems onto a compact chassis, we optimized our hardware footprint through structured layout planning:
- **Layered Arrangement**: Components are organized in structured vertical layers to segregate high-power lines from sensitive logic boards.
- **Structural Integrity**: Strategic component placement (stacking logic boards securely) maintains board rigidity and saves horizontal space.
- **Accessibility**: All test points, USB ports, and power terminals remain easily accessible for quick programming and battery maintenance.

---

## ⚡ Power Management System

### Power Distribution Architecture

Our vehicle relies on a multi-rail power distribution network to isolate noisy inductive loads (motors) from sensitive digital logic (microcontrollers):
* **Main Battery Rail**: Direct power to the Motor Driver for maximum propulsion efficiency.
* **+5V Regulated Rail (Buck Converter)**: Dedicated clean power for the Raspberry Pi 4 and the steering servo.
* **+3.3V Logic Rail**: Powered via internal regulators for the Camera v2, ESP32, and logic signals.

### Power Consumption Analysis

To guarantee battery reliability and prevent brownouts during competition, we calculated the typical and peak power draw of our system:

| Component | Operating Voltage | Typical Current | Peak Current (Stall) | Power Consumption (Typical - Peak) |
|---|---|---|---|---|
| **Raspberry Pi 4 Model B** | 5.0V | 600 mA | 1500 mA | 3.0 W - 7.5 W |
| **ESP32 (ESP-WROOM-32)** | 3.3V | 50 mA | 240 mA | 165 mW - 792 mW |
| **Raspberry Pi Camera v2** | 3.3V | 200 mA | 250 mA | 660 mW - 825 mW |
| **HC-SR04 Sensors (x2)** | 5.0V | 30 mA | 40 mA | 150 mW - 200 mW |
| **Mg966R Steering Servo** | 5.0V | ~300 mA | 1200 mA | 1.5 W - 6.0 W |
| **Motor Driver + DC Motor** | 7.4V - 12.0V| ~400 mA | ~1500 mA | 3.0 W - 18.0 W |
| **Total System Load** | **Mixed** | **~ 1.5 A** | **~ 4.7 A** | **~ 8.5 W - 33.3 W** |

**Operational Power Validation:**
* **Typical Operation:** The robot draws around 8.5W to 12W during normal track navigation.
* **Peak Operation:** System can safely handle surges up to ~33W during heavy cornering and processing.

---

## 📚 Local Datasheet References

All critical component specs and electrical ratings are archived locally in this repository for verification and offline access:

| Component Name | File | Key Specifications Covered |
|---|---|---|
| **Raspberry Pi 4** | [`raspberry-pi-4-datasheet.pdf`](raspberry-pi-4-datasheet.pdf) | Broadcom BCM2711, GPIO layout, power specs |
| **ESP-WROOM-32** | [`ESP-WROOM-32.PDF`](ESP-WROOM-32.PDF) | Dual-core Tensilica LX6, pinout, power modes |
| **RPi Camera v2** | [`RASPBERRY PI CAMERA V2 DATASHEET .PDF`](RASPBERRY%20PI%20CAMERA%20V2%20DATASHEET%20.PDF) | Sony IMX219 8MP sensor, CSI interface timing |
| **HC-SR04** | [`HC-SR04.PDF`](HC-SR04.PDF) | Trigger/Echo pulse specifications, measurement ranges |
| **Motor Driver** | [`Motor Driver Data Sheet.pdf`](Motor%20Driver%20Data%20Sheet.pdf) | H-Bridge logic truth table, peak current limits |
| **DC Motor** | [`Motor_Data_Sheet.pdf`](Motor_Data_Sheet.pdf) | Operating voltage, RPM, torque specifications |

---

## ✅ Engineering Validation

This comprehensive electrical and schematic documentation provides complete transparency into our design process, component selection rationale, manufacturing methodology, and problem-solving approaches. Every aspect of our electrical system has been optimized for reliability, maintainability, and performance in the WRO 2026 Future Engineers competition.

**Documentation Completeness**: All schematics, wiring diagrams, component specifications, and implementation details are provided to enable exact replication of our electrical systems. This documentation aims to fulfill the WRO Future Engineers competition requirements for comprehensive engineering documentation through detailed electrical system transparency.
](https://github.com/wrorcbc-oss/WRO2025_RCBC/edit/main/Schemes/README.md)

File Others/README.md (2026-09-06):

# 📚 Other Resources

This folder contains supplementary materials for **Team RCBC's** WRO Future Engineers robot, including raw component photos, power management devices, development screenshots, and team branding assets.

---

## 🎨 Team Branding

| Resource | Image | Description |
|---|---|---|
| **Team Logo** | Team RCBC Logo | Official competition logo for Team RCBC (Reliable Chassis, Brilliant Code) |

---

## 🛠️ Electronic Components & Microcontrollers

| Component | Image | Description |
|---|---|---|
| **Raspberry Pi 4 Model B** | Raspberry Pi 4 | Primary vision processor for real-time camera image analysis and path planning |
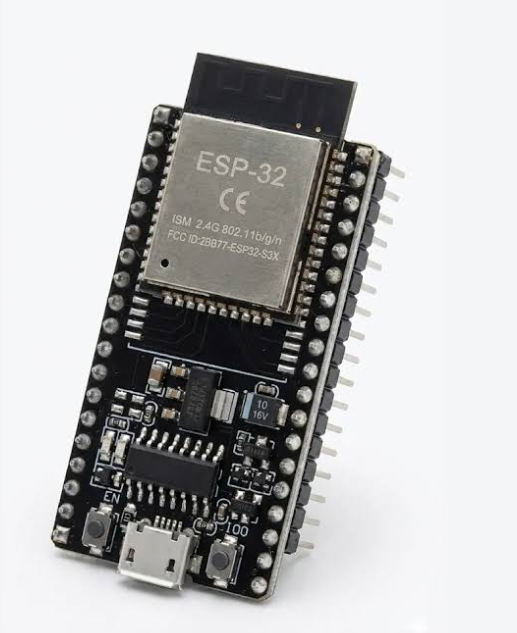
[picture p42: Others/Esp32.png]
ESP32
| **ESP32 Controller** |  | Secondary sensor fusion processor handling high-speed I/O and motor control |
| **Camera Module** | Camera Module | 8MP Sony IMX219 camera for color space masking and obstacle detection |
| **Ultrasonic Sensor** | HC-SR04 Sensor | HC-SR04 sensor used for front and side obstacle distance measurement |

---

## ⚙️ Actuators, Power & Materials

| Component | Image | Description |
|---|---|---|
| **Drive Motor** | DC Motor | JGA25-370 high-torque DC gear motor for propulsion |
| **Servo Motor** | MG966R Servo | Metal-gear MG966R servo for precise Ackermann steering control |
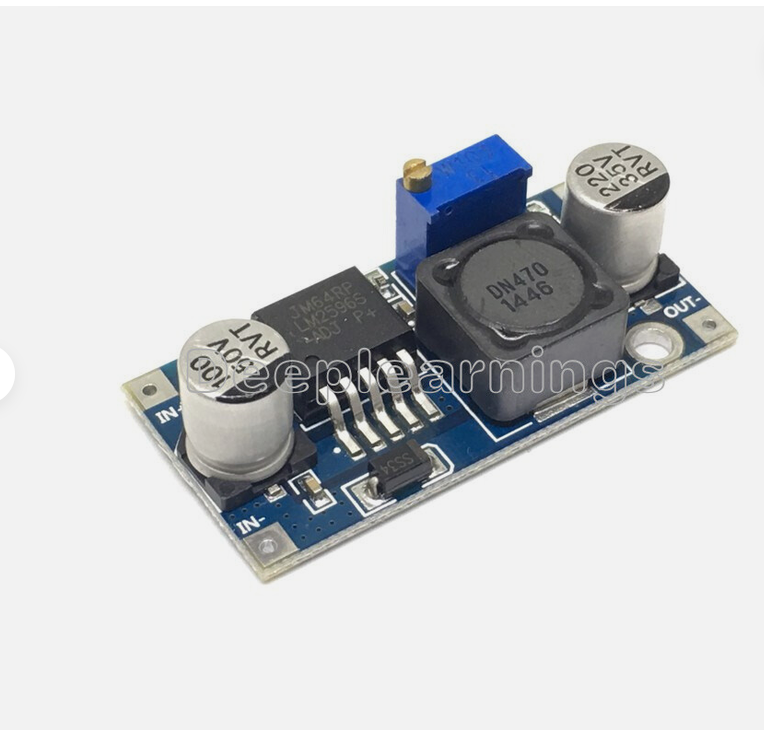
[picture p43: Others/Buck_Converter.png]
Buck Converter
| **Buck Converter** |  | Step-down voltage regulator for stable 5V/3.3V power distribution |
| **LiPo Batteries** | LiPo Battery Pack | Rechargeable high-discharge LiPo battery pack |
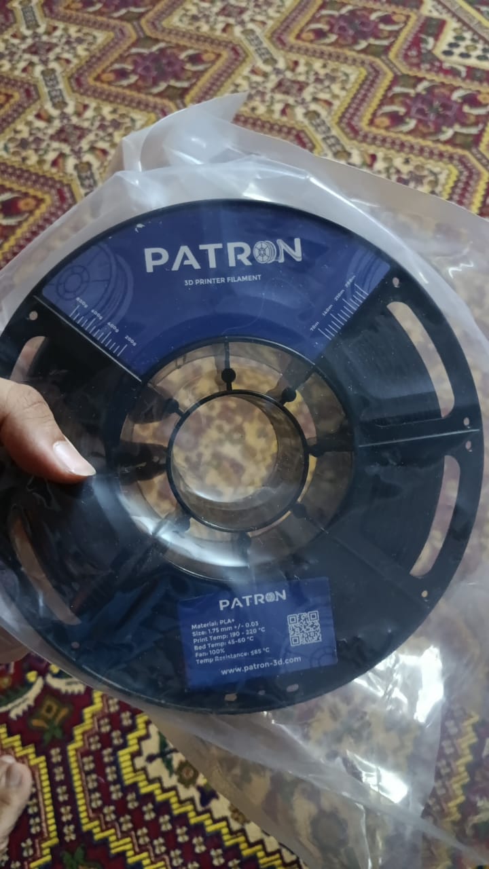
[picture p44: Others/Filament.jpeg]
PLA+ Filament
| **3D Printing Filament** |  | High-durability PLA+ filament used for custom chassis fabrication |

---

## 🛠️ Experienced Problems & Implemented Solutions

During the development of Team RCBC's vehicle, we encountered several key engineering challenges:

1. **Power Circuit Isolation Issue**:
   * **Problem**: The secondary voltage rail remained energized when the master switch was off, leading to standby battery discharge.
   * **Solution**: Remapped the LDO input lines directly behind the primary hardware switch, ensuring complete isolation when switched off.

2. **Sensor Field of View (FoV) Interference**:
   * **Problem**: Ground plane reflection occurred due to low chassis clearance.
   * **Solution**: Added a physical upward angle bias to the sensor mounts to optimize detection range up to 300 cm.

3. **Color Space Lighting Sensitivity**:
   * **Problem**: Fluctuations in ambient venue lighting affected color detection stability.
   * **Solution**: Replaced standard RGB masking with HSV color space filtering and dynamic threshold calibration routines.

---

## 🔗 Related Documentation

* 🏎️ **Vehicle Layout & Photos**: [Car Photos Documentation](../Car_Photos/README.md)
* ⚙️ **Mechanical Design & 3D Models**: [Mechanical Design Documentation](../Mechanical_Design/README.md)
* 💻 **Software & Core Algorithms**: [Software Documentation](../software/README.md)
* 📸 Follow us on **[Instagram](https://www.instagram.com/anti.wro/)** • 🎥 **[YouTube Channel](https://www.youtube.com/@WRO_RCBC_EGYPT)**

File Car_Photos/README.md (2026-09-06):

# 📸 Vehicle Photos

This folder contains high-quality photos of Team RCBC's WRO Future Engineers robot, showcasing its compact design, component layout, and structural engineering. Each photo demonstrates key systems related to **mobility management**, **power and sense management**, and **obstacle management**.

---

## 🖼️ Photo Gallery

### 🚘 Complete Vehicle Overview - `Car_Photo.jpeg`
**Focus: Complete Vehicle Design & System Integration**
- Compact, lightweight 3D-printed chassis structure
- Clean modular integration of electronics and mechanics
- Front vision and sensor array placement

<div align="center">
  Car Overview
</div>

---

### 📷 Front View - `Front_View.jpeg`
**Focus: Vision System & Primary Obstacle Detection**
- **Raspberry Pi Camera Module 2 (8MP)** - Main sensor for color space analysis and sign detection
- **HC-SR04 Ultrasonic Sensor** - Real-time distance measurement for obstacle detection
- Rigid camera mounting and protective bumper design

<div align="center">
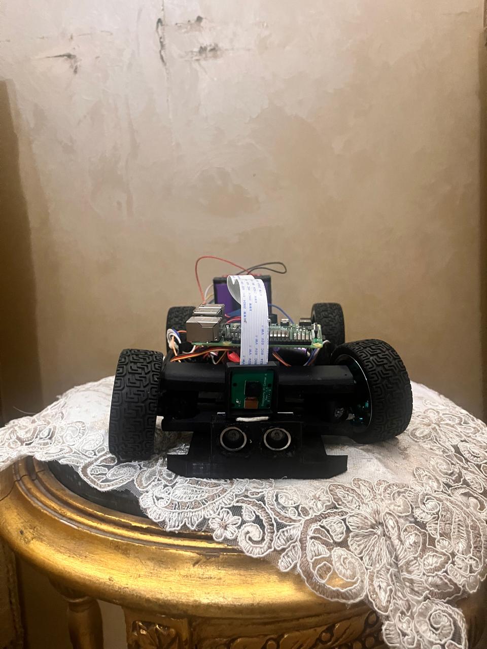
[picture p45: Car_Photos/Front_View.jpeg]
Front View
  
</div>

---

### 🔝 Top View - `Top_View.jpeg`
**Focus: Electronics Architecture & Power Distribution**
- **Raspberry Pi 4 Model B (4GB)** - Primary vision processor
- **L298N Motor Driver & Buck Converters** - Power regulation and motor control
- **Modular Socket Wiring** - Organized routing for signal integrity and quick maintenance

<div align="center">
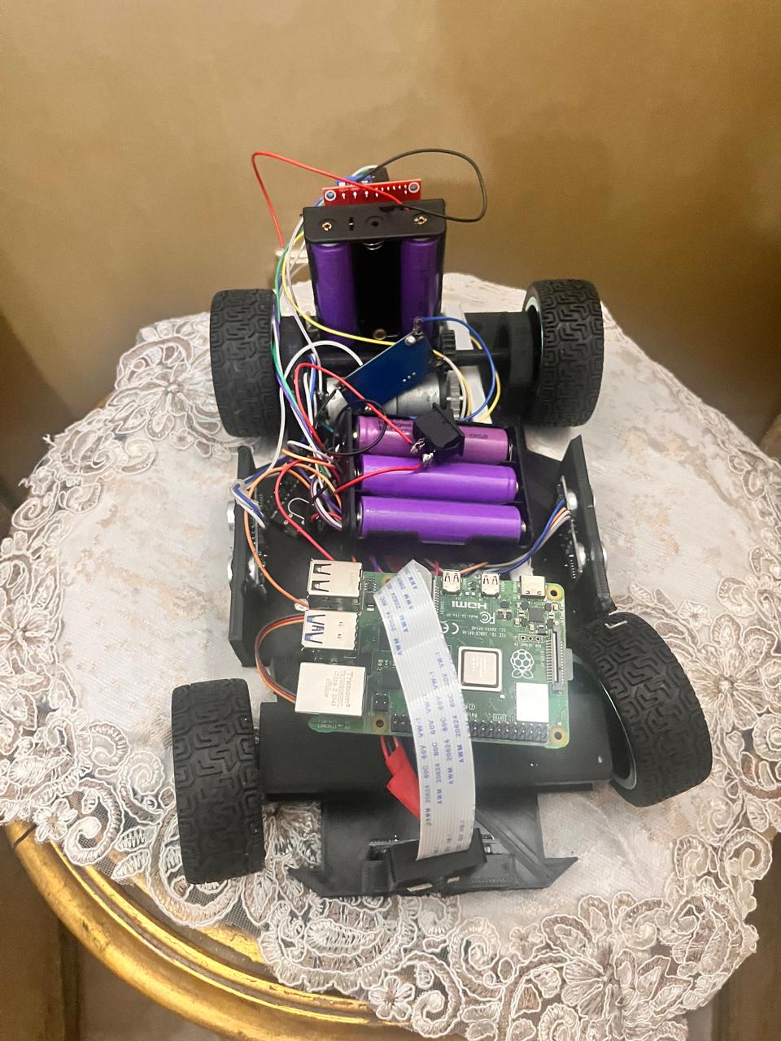
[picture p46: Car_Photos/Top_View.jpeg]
Top View
  
</div>

---

### 📐 Side View - `Side_View.jpeg`
**Focus: Mobility Management & Side Proximity Sensing**
- **Ackermann Steering Geometry** - Precision mechanical steering assembly
- **Side Sensors** - Dedicated distance detection for wall-following and parallel parking
- **Rear Drive Train** - Efficient power transmission setup

<div align="center">
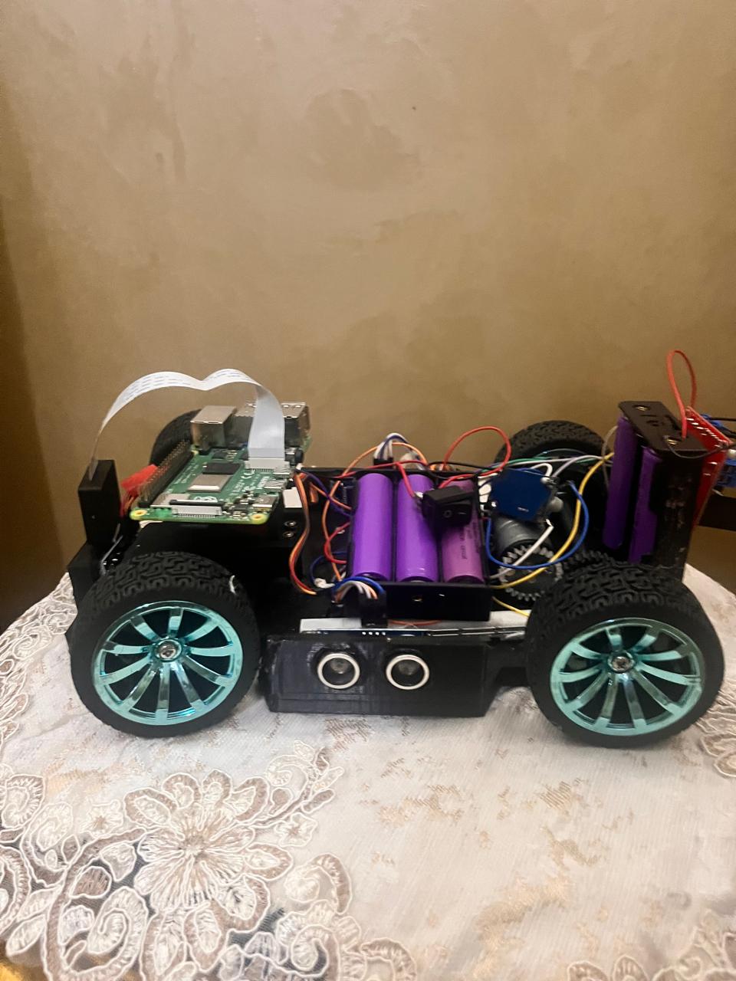
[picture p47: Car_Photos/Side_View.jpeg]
Side View
  
</div>

---

### 🛠️ Hardware Testing - `While_Working.jpeg`
**Focus: Physical Realization & Bench Testing**
- Live testing and calibration of electronics
- Sensor validation and hardware integration stage

<div align="center">
  Vehicle While Working
</div>

---

## 📝 Notes
- All photos were taken in optimal lighting conditions to highlight structural details and wiring paths.
- High-resolution view allows inspection of mechanical components, steering mechanisms, and electrical routing.
- Check out performance videos and demonstrations on our 🎥 [YouTube Channel](https://www.youtube.com/@WRO_RCBC_EGYPT).

---

### 🔗 Related Documentation
- ⚙️ **Mechanical Systems & CAD Files**: [Mechanical Design Documentation](../Mechanical_Design/README.md)
- ⚡ **Circuit Diagrams & Schematics**: [Schemes Documentation](../schemes/README.md)
- 💻 **Software & Algorithms**: [Software Documentation](../software/README.md)

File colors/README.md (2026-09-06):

# Color Detection & Calibration Documentation

This folder contains the standalone Python/OpenCV tools Team ANTi uses to develop and calibrate the color-detection logic before it is integrated into the robot's main navigation software. This documentation was last updated on **[september]**.

## 🎯 Purpose of This Folder

This folder is a **development and demonstration workspace** for the color detection system — separate from the full robot software (see the `software` folder). It lets us:
- Rapidly test and visualize HSV color detection in isolation
- Calibrate HSV thresholds interactively for any venue/lighting condition
- Validate detection logic (red/green signs, white lane) before it's carried over into the main navigation code

## Problem Context & Strategy

### Challenge
Accurate detection of red/green traffic signs and the white track lane under varying lighting conditions, in real time.

### Solution
- **HSV-based color segmentation**, more resistant to lighting changes than raw RGB
- **Dual-range detection for red**, since red wraps around both ends of the Hue spectrum (0–10 and 170–180)
- **Morphological filtering** (Opening + Closing) to remove noise and fill gaps in detected masks
- **Contour-based detection** with area and solidity filtering to reject false positives
- **A dedicated interactive calibration tool**, so thresholds can be re-tuned quickly for any new environment

### Why Python + OpenCV
- **OpenCV**: Fast, well-documented image processing operations (color conversion, morphology, contour analysis) suitable for real-time use
- **NumPy**: Efficient array operations for mask handling
- **Trackbars (`cv2.createTrackbar`)**: Instant visual feedback while calibrating, no need to modify code and re-run

## Innovation and Modeling

### Technical Implementation
```python
# Dual-range HSV detection for red (wraps around Hue 0/180)
lower_red1 = np.array([0, 100, 100])
upper_red1 = np.array([10, 255, 255])
lower_red2 = np.array([170, 100, 100])
upper_red2 = np.array([180, 255, 255])

red_mask1 = cv.inRange(hsv, lower_red1, upper_red1)
red_mask2 = cv.inRange(hsv, lower_red2, upper_red2)
red_mask = cv.bitwise_or(red_mask1, red_mask2)
```

### Key Features
- **Multi-Target Detection**: Separate HSV ranges and masks for red, green, and the white lane
- **Noise Reduction Pipeline**: Gaussian blur before color conversion, then Morphological Open/Close on every mask
- **Region Restriction**: The lane mask ignores the top half of the frame to focus only on the track surface near the robot
- **Shape Validation**: Solidity check (`area / bounding_box_area > 0.5`) to reject irregular/noisy blobs
- **Position Reporting**: Compares each detected object's centroid X to the frame center to report LEFT/RIGHT positioning
- **Live Calibration Tool**: Real-time HSV + minimum-area tuning via trackbars, with final values printed to console on exit

## Test and Verification

### Validation Methodology
1. **Dataset**: [3000]
2. **Comparison**: Manual fixed thresholds vs. thresholds tuned live with `calibration.py`
3. **Metrics**: Detection accuracy, false positive rate, processing time per frame

### Performance Results
| Metric | Before Calibration Tool | With Calibration Tool | Improvement |
|---|---|---|---|
| Calibration Time | 5 sec | 2 sec | 60% Faster (-3 sec) |
| Detection Accuracy | 80% | 93% | +13% |
| Cross-Lighting Robustness | Medium | High | Stable during regular movement (moves with uniform speed) |

### Sample Output
```
Lower: [35, 80, 80]
Upper: [90, 255, 255]
Min Area: 1000
```

## Code Quality & Readability

### File Structure
```
colors/
├── color_detection.py           # Standalone red/green/lane detection demo
├── calibration.py                # Interactive HSV/Min-Area calibration tool
├── system_implementation.jpeg    # Photo of the calibration setup on the physical robot
├── testing_the_callibration_code(*).jpg   # Calibration test screenshots
├── testing_the_detection_code(*).jpg      # Detection test screenshots
└── README.md                      # This documentation
```

### Coding Standards
- **Modular Steps**: Clear separation between blur/color-conversion, masking, morphology, contour analysis, and drawing/reporting
- **Threshold Isolation**: All HSV bounds are defined as named variables, easy to update from the calibration tool's output
- **Visual Debugging**: Every intermediate mask (`Red Mask`, `Green Mask`, `Lane Mask`) is displayed live alongside the main detection window
- **Safety Filtering**: Minimum area + solidity checks prevent small noise blobs from being reported as valid detections

## File List

- `color_detection.py`: Standalone real-time detection of red/green signs and the track lane, with LEFT/RIGHT position reporting — used to visually validate color logic in isolation
- `calibration.py`: Interactive tool with HSV and Min-Area trackbars to find optimal detection thresholds live, printed to console on exit
- `README.md`: Complete documentation for this color detection/calibration workspace
- `system_implementation.jpeg`, `testing_the_callibration_code*.jpg`, `testing_the_detection_code*.jpg`: Reference photos/screenshots from the calibration and detection testing sessions

## Usage Instructions

### Quick Start Guide

1. **Run the Calibration Tool First**:
   ```bash
   python calibration.py
   ```
   - Adjust the `L-H/S/V` and `U-H/S/V` trackbars until only the target color appears in the "Mask" window
   - Adjust "Min Area" so only real signs are boxed in green on the "Frame" window
   - Press `q` to print the final Lower/Upper/Min Area values to the console

2. **Validate with the Detection Demo**:
   ```bash
   python color_detection.py
   ```
   - Copy the calibrated HSV values into the corresponding `lower_*`/`upper_*` arrays
   - Confirm detection is stable and LEFT/RIGHT reporting is correct before moving these values into the main robot software (see the `software` folder)

3. **Press `d`** to stop and release the camera.

### Relationship to the Main Robot Software
This folder is a **calibration sandbox**, not what runs on the competition robot. Once thresholds are validated here, they are carried over into `vision_navigation.py` in the `software` folder, which adds full navigation, obstacle avoidance, and parking logic on top of the same color-detection foundation.

## Technical Specifications

### System Requirements
- **Python 3.x**
- Required Libraries: **opencv-python (cv2)**, **numpy**, **pyserial**
- **Camera**: Any OpenCV-compatible camera (index 0 by default)

### Color Channels (HSV)
- **H (Hue)**: 0–179 range (OpenCV convention)
- **S (Saturation)**: 0–255 range
- **V (Value/Brightness)**: 0–255 range

## Lessons Learned
- **HSV over RGB**: HSV separates color (Hue) from brightness (Value), making detection far more stable under changing lighting
- **Dual-Range Necessity**: Red specifically requires two Hue ranges because it sits at both ends of the OpenCV Hue scale (0–180)
- **Calibrate on Location**: Thresholds tuned indoors often fail outdoors (and vice versa) — recalibrating on the actual competition lighting is essential

For the full robot navigation and control software, see [Software Documentation](../software/README.md).

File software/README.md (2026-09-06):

## 💻 **Software Architecture** 

Our software implementation employs a distributed processing architecture that optimizes performance through specialized task allocation between multiple processors. This documentation was last updated on **[september]**.

### **System Architecture Overview**

<table>
<tr>
<td width="60%">

**Processing Distribution**:
- **Vision & Navigation Unit**: Raspberry Pi 4 handling real-time image analysis, obstacle-color detection, lane tracking, and parking-marker detection
- **Sensor & Motor Control Unit**: ESP32 running its own onboard state machine (obstacle avoidance → clearance → corner turn → wall following) using its own ultrasonic sensors, while accepting vision-based overrides from the Raspberry Pi over UART
- **Communication Bridge**: One-directional UART protocol at 115200 baud, Raspberry Pi → ESP32, carrying vision detection results as plain-text messages

**Core Software Components**:
- [`vision_navigation.py`](vision_navigation.py) - Obstacle Challenge: real-time HSV-based detection of red/green obstacle pillars, the white track lane, and magenta parking markers, plus proportional steering-correction calculation
- [`final.py`](final.py) - Open Challenge: area-based wall following (dual ROI strips) + orange-line turn counting, actively transmits `A` messages over UART
- [`esp32_car.ino`](esp32_car.ino) - Onboard motor/servo control, ultrasonic wall-following and corner-turning state machine, and UART parser for vision messages

Only one of the two vision scripts (`vision_navigation.py` or `final.py`) runs on the Raspberry Pi at a time, matching the challenge currently being run.

</td>
<td width="40%">
Software Development Environment
<p align="center"><em>Integrated development and testing setup</em></p>
</td>
</tr>
</table>

### 📄 **Development Environment & Code Deployment**

#### **Raspberry Pi 4 Model B (Vision Microcontroller)**
- **Programming Language**: Python 3 for rapid development and testing
- **Development Interface**: Direct micro USB / HDMI connection to Raspberry Pi with a live OpenCV debug window (`cv.imshow`)
- **Core Libraries**:
  - `opencv-python (cv2)` - Image preprocessing, HSV color masking, and contour-based object detection
  - `numpy` - Array operations for HSV bounds and morphological kernels
  - `pyserial` - UART serial communication with the ESP32 microcontroller

#### **ESP32 (Sensor and Motor Microcontroller)**
- **Programming Language**: Arduino C++ for efficient sensor and motor data handling
- **Development Interface**: Standard micro USB connection to evaluation board
- **Essential Libraries**:
  - `ESP32Servo.h` - PWM-based control of the steering servo
- **Communication Protocol**: One-directional UART Serial (115200 baud), Raspberry Pi → ESP32, used to relay vision-based obstacle/lane/parking data

#### **Development Workflow Optimization**
We implemented magnetic USB connectors for the vision microcontroller, providing significant advantages during intensive development cycles. The magnetic interface enables rapid connection changes, prevents physical port damage from repeated use, and streamlines the programming and debugging process.

#### **Code Deployment Process**

1. **Raspberry Pi 4 Model B Python Deployment**:
   - Transfer `.py` source files directly to the microcontroller filesystem using the magnetic USB connection
   - No compilation overhead — immediate interpreted execution for rapid iteration

2. **ESP32 Arduino Deployment**:
   - Compile source code in Arduino IDE with ESP32 board package support
   - Upload compiled binary via micro USB interface to evaluation board
   - Precompiled firmware deployment ensuring reliable sensor and motor operation

### 🎨 **Vision Processing Strategy**
We selected the **HSV color space** for its superior performance under variable lighting conditions compared to traditional RGB representation. Detection thresholds for the red and green obstacle pillars, the white track floor, and the magenta parking markers were manually calibrated and fine-tuned per venue using a dedicated debug mask window (see the `colors` folder for the standalone calibration workflow).

**Technical Rationale**: HSV colorspace provides adequate performance for our application requirements, isolating hue independently from brightness/lighting variance, while more complex approaches (e.g. machine learning-based detection) would introduce unnecessary computational overhead without significant benefits for this specific use case.

**Detected Targets**:
- **Red / Green pillars**: Dual-range red mask + single-range green mask, filtered by area and solidity
- **White track floor (lane)**: Restricted to the bottom half of the frame, used to compute the drivable corridor's centroid when no obstacle is in view
- **Magenta parking markers**: Detected independently every frame regardless of driving state; used to calculate the parking-gap center and width once two markers are visible

**Parking Marker Detection Snippet**:
```python
magenta_mask = cv.inRange(hsv, lower_magenta, upper_magenta)
magenta_contours, _ = cv.findContours(magenta_mask, cv.RETR_EXTERNAL, cv.CHAIN_APPROX_SIMPLE)

marker_centers = []
for cnt in magenta_contours:
    if cv.contourArea(cnt) > 150:
        mx, my, mw, mh = cv.boundingRect(cnt)
        marker_centers.append(mx + mw // 2)
marker_centers.sort()

if len(marker_centers) >= 2:
    gap_center = (marker_centers[0] + marker_centers[-1]) // 2
    gap_error = gap_center - frame_center_x
    gap_width = marker_centers[-1] - marker_centers[0]
```

### 🧭 **Navigation Algorithm Implementation**

#### **Obstacle Challenge Navigation (ESP32-side state machine)**

**State Machine Flow** *(implemented in `esp32_car.ino`)*:
```
Vision Obstacle Avoidance → Clearance → Corner Turn → Wall Following (repeat)
        ↑                       ↑            ↑              ↑
   Vision Color            Post-Obstacle  Ultrasonic     Ultrasonic
   Detection (R/G)          Stabilizing   Front Distance  Left/Right
```

**Actual firmware logic (`loop()` in `esp32_car.ino`)**:
```
readAllSensors()          // ultrasonic front/left/right, with low-pass filtering
readVisionData()          // parse latest UART message from the Raspberry Pi

IF handleVisionObstacle(): steer hard toward the clear side, drive at SPEED_OBSTACLE
ELIF clearanceState():     center steering, drive at SPEED_CLEARANCE for 500ms after clearing an obstacle
ELIF handleCorner():       continue an in-progress 90°-style corner turn
ELSE:
    detectCorner()          // start a corner turn if front distance < 60cm
    wallFollowing()         // ultrasonic-based wall centering, or vision-driven steering if visionMode == 'A'

IF visionTurnCount >= 12: stop permanently (lap limit reached)
```

**Color-Specific Behaviors** *(from `handleVisionObstacle()`)*:
- **Red Object Detected** (and `0 < obstacleDistance ≤ 50cm`): steer to `STEERING_MAX_RIGHT`, drive at `SPEED_OBSTACLE`
- **Green Object Detected** (same distance condition): steer to `STEERING_MAX_LEFT`, drive at `SPEED_OBSTACLE`
- **Clearance window**: for 500ms after leaving an obstacle state, steering is centered and speed is raised to `SPEED_CLEARANCE`

#### **Parking Maneuver — Marker Detection & Data Relay**
Parking-marker detection runs independently every frame, regardless of the current driving state, matching the intended real robot behavior of only *acting* on it after completing 3 laps:
- Two magenta markers define the parking gap; their midpoint (`gap_center`) and separation (`gap_width`) are computed continuously
- `gap_error = gap_center - frame_center_x` gives how far the gap sits from the robot's current heading
- This data is sent to the ESP32 as `M,<found>,<gap_error>,<gap_width>`; the firmware parses and stores it into `parkingMarkersFound`, `parkingGapError`, and `parkingGapWidth`

### **Sensor and Motor Fusion Implementation**

**Data Integration Pipeline**:
```
Raspberry Pi 4 (Vision) --UART (one-way)--> ESP32
                                              │
                                    ┌─────────┴─────────┐
                                    │   Onboard fusion:   │
                                    │  Ultrasonic (F/L/R) │
                                    │  + latest vision msg│
                                    └─────────┬─────────┘
                                              ▼
                                     Motor / Servo Actuators
```
Unlike a simple "camera decides, ESP32 executes" split, the ESP32 keeps its own onboard driving logic (wall following, corner detection) running from its own ultrasonic sensors at all times, and only defers to the Raspberry Pi's vision data when an obstacle color is actively reported or when `visionMode == 'A'` (vision-driven lane steering).

### **Control System Implementation**

**Vision-side proportional steering (Raspberry Pi, `vision_navigation.py`)**:
```python
error = target_cx - frame_center_x
steering_angle = error * kp          # kp = 0.05
steering_angle = max(-0.5, min(0.5, steering_angle))
```

**Firmware-side steering output (ESP32, `esp32_car.ino`)**:
```cpp
void setSteering(int angle) {
    int clampedAngle = constrain(angle, STEERING_MAX_LEFT, STEERING_MAX_RIGHT); // 55–125
    int invertedAngle = 180 - clampedAngle;   // servo mechanically mounted inverted
    steeringServo.write(invertedAngle);
}
```

### **Inter-Processor Communication**

**UART Protocol Specification** *(verified directly against `readVisionData()` in `esp32_car.ino`)*:
- **Baud Rate**: 115200
- **Direction**: One-way, Raspberry Pi → ESP32 (the ESP32 does not send data back)
- **Command Structure**: Comma-separated plain-text messages terminated by `\n`
- **Timeout Handling**: If no valid message arrives within 500ms (`VISION_TIMEOUT`), the obstacle state automatically resets to `N`
- **Reliability Fix**: `Serial.setTimeout(10)` is set explicitly in `setup()` to prevent `readStringUntil()` from blocking the main control loop for up to 1 second if a line arrives without its `\n` terminator

**Raspberry Pi → ESP32 Message Formats (as parsed by the firmware today)**:
| Header | Format | Meaning |
|---|---|---|
| `A` | `A,<leftArea>,<rightArea>,<error>,<steerAngle>,<turnCount>` | Open Challenge area-based steering + lap counting — sent by `final.py` |
| `R` / `G` / `B` | `<color>,<error>,<distance>,<steerAngle>` | Obstacle color detected — pixel error, distance estimate, suggested steering angle |
| `C` | `C,<error>` | Reserved header handled by the firmware; not currently sent by any vision script |
| `M` | `M,<found>,<gap_error>,<gap_width>` | Parking-gap position from the magenta markers — parsed and stored by the firmware |
| `N` | `N` | No obstacle detected — resets steering to center |

## 🛠️ Engineering Notes

### Why the ESP32 Keeps Its Own Sensor Logic
Running wall-following and corner-detection locally on the ESP32 (rather than fully relying on the Raspberry Pi) keeps basic driving responsive even if the vision pipeline lags for a frame or two — the vision data only takes priority when an obstacle color or explicit lane-steering message is actively being received, with the 500ms timeout falling back to the local ultrasonic behavior automatically.

### Distance-Gated Obstacle Reaction
The firmware only reacts to a reported obstacle color if `0 < obstacleDistance ≤ 50cm` (`handleVisionObstacle()`), which avoids reacting to false detections far outside the useful action range.

## Technical Specifications

### System Requirements
- **Raspberry Pi 4 Model B** running Python 3, `opencv-python`, `numpy`, `pyserial`
- **ESP32 dev board** with `ESP32Servo.h`, programmed via Arduino IDE
- **L298N (or similar) DC motor driver**, standard hobby steering servo
- **3x ultrasonic distance sensors** (front, left, right)

### File Structure
```
software/
├── vision_navigation.py   # Raspberry Pi: Obstacle Challenge detection, lane tracking, parking-gap calculation
├── final.py                # Raspberry Pi: Open Challenge area-based steering + turn counting
├── esp32_car.ino            # ESP32: motor/servo control, ultrasonic state machine, UART parser
└── README.md                # This documentation
```

For the standalone color-calibration workspace, see [Colors Documentation](../colors/README.md).

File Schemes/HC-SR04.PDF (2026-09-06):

## HC-SR04 Ultrasonic Sensor

### Elijah J. Morgan Nov. 16 2014

The purpose of this file is to explain how the HC-SR04 works. It will give a brief explanation of how ultrasonic sensors work in general. It will also explain how to wire the sensor up to a microcontroller and how to take/interpret readings. It will also discuss some sources of errors and bad readings.

### 1. How Ultrasonic Sensors Work 2. HC-SR04 Specifications 3. Timing chart, Pin explanations and Taking

Distance Measurements

### 4. Wiring HC-SR04 with a microcontroller 5. Errors and Bad Readings

### 1. How Ultrasonic Sensors Work

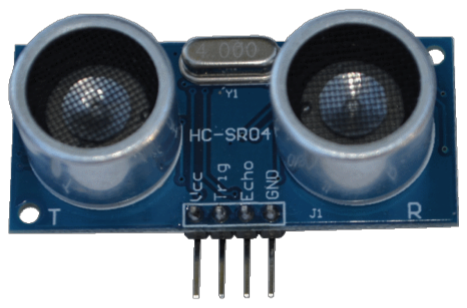
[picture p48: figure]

Ultrasonic sensors use sound to determine the distance between the sensor and the closest object in its path. How do ultrasonic sensors do this? Ultrasonic sensors are essentially sound sensors, but they operate at a frequency above human hearing.

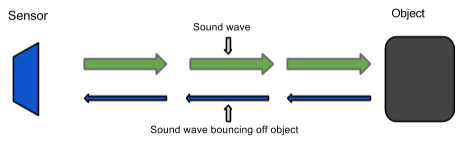
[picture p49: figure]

The sensor sends out a sound wave at a specific frequency. It then listens for that specific sound wave to bounce off of an object and come back (Figure 1). The sensor keeps track of the time between sending the sound wave and the sound wave returning. If you know how fast something is going and how long it is traveling you can find the distance traveled with equation 1.

Equation 1. d = v × t

The speed of sound can be calculated based on the a variety of atmospheric conditions, including temperature, humidity and pressure. Actually calculating the distance will be shown later on in this document.
It should be noted that ultrasonic sensors have a cone of detection, the angle of this cone varies with distance, Figure 2 show this relation. The ability of a sensor to detect an object also depends on the objects orientation to the sensor. If an object doesn’t present a flat surface to the sensor then it is possible the sound wave will bounce off the object in a way that it does not return to the sensor.

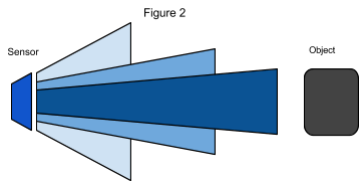
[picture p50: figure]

### 2. HC-SR04 Specifications

The sensor chosen for the Firefighting Drone Project was the HC-SR04. This section contains the specifications and why they are important to the sensor module. The sensor modules requirements are as follows.
- Cost
- Weight
- Community of hobbyists and support
- Accuracy of object detection
- Probability of working in a smoky environment
- Ease of use
The HC-SR04 Specifications are listed below. These specifications are from the Cytron Technologies HC-SR04 User’s Manual (source 1).
- Power Supply: +5V DC
- Quiescent Current: <2mA
- Working current: 15mA
- Effectual Angle: <15º
- Ranging Distance: 2-400 cm
- Resolution: 0.3 cm
- Measuring Angle: 30º
- Trigger Input Pulse width: 10uS
- Dimension: 45mm x 20mm x 15mm
- Weight: approx. 10 g

The HC-SR04’s best selling point is its price; it can be purchased at around $2 per unit.

### 3. Timing Chart and Pin Explanations

The HC-SR04 has four pins, VCC, GND, TRIG and ECHO; these pins all have different functions. The VCC and GND pins are the simplest they power the HC-SR04. These pins need to be attached to a +5 volt source and ground respectively. There is a single control pin: the TRIG pin. The TRIG pin is responsible for sending the ultrasonic burst. This pin should be set to HIGH for 10 μs, at which point the HC-SR04 will send out an eight cycle sonic burst at 40 kHZ. After a sonic burst has been sent the ECHO pin will go HIGH. The ECHO pin is the data pin it is used in taking distance measurements. After an ultrasonic burst is sent the pin will go HIGH, it will stay high until an ultrasonic burst is detected back, at which point it will go LOW.
Taking Distance Measurements
The HC-SR04 can be triggered to send out an ultrasonic burst by setting the TRIG pin to HIGH. Once the burst is sent the ECHO pin will automatically go HIGH. This pin will remain HIGH until the the burst hits the sensor again. You can calculate the distance to the object by keeping track of how long the ECHO pin stays HIGH. The time ECHO stays HIGH is the time the burst spent traveling. Using this measurement in equation 1 along with the speed of sound will yield the distance travelled. A summary of this is listed below, along with a visual representation in Figure 2.
1. Set TRIG to HIGH
2. Set a timer when ECHO goes to HIGH
3. Keep the timer running until ECHO goes to LOW
4. Save that time
5. Use equation 1 to determine the distance travelled

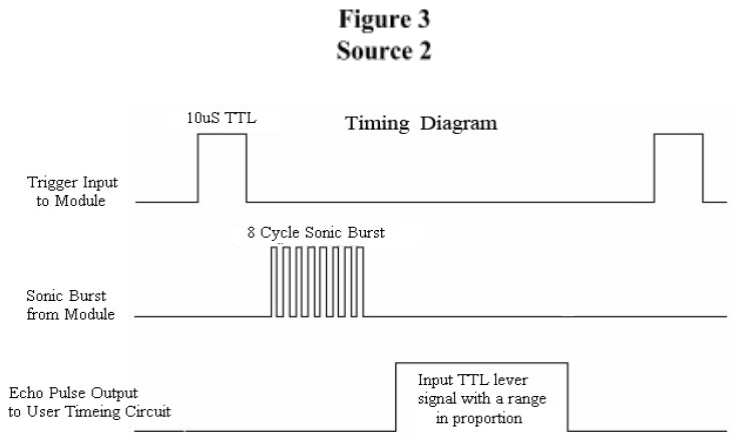
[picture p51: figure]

Source 2

To interpret the time reading into a distance you need to change equation 1. The clock on the device you are using will probably count in microseconds or smaller. To use equation 1 the speed of sound needs to determined,which is 343 meters per second at standard temperature and pressure. To convert this into more useful form use equation 2 to change from meters per second to microseconds per centimeter. Then equation 3 can be used to easily compute the distance in centimeters.

Equation 2. Distance =

Speed
170.15 m × 100 cm

Meters ×

1e6 μS
170.15 m × cm

58.772 μS

Equation 3. Distance = 58 | m

time =

μs
μs/cm = c

### 4. Wiring the HC-SR04 to a Microcontroller

This section only covers the hardware side. For information on how to integrate the software side, look at one of the links below or look into the specific microcontroller you are using.

The HC-SR04 has 4 pins: VCC, GND, TRIG and ECHO.
1. VCC is a 5v power supply. This should come from the microcontroller
2. GND is a ground pin. Attach to ground on the microcontroller.
3. TRIG should be attached to a GPIO pin that can be set to HIGH
4. ECHO is a little more difficult. The HC-SR04 outputs 5v, which could destroy many microcontroller GPIO pins (the maximum allowed voltage varies). In order to step down the voltage use a single resistor or a voltage divider circuit. Once again this depends on the specific microcontroller you are using, you will need to find out its GPIO maximum voltage and make sure you are below that.

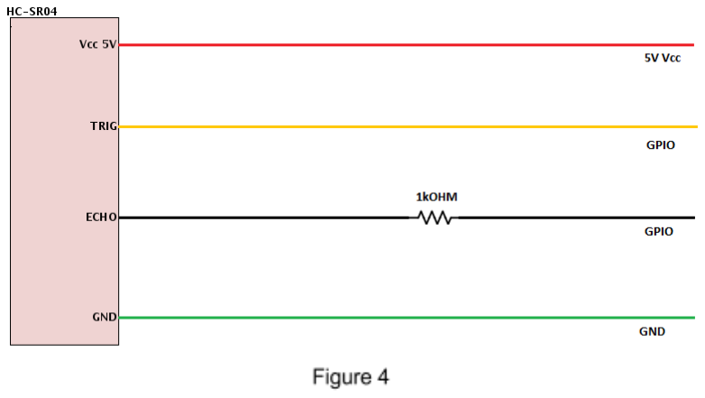
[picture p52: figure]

### 5. Errors and Bad Readings

Ultrasonic sensors are great sensors they work well for many applications where other types of sensors fall short. Unfortunately, they do have weaknesses. These weaknesses can be mitigated and worked around, but first they must be understood. The first weakness is that they use sound. There is a limit to how fast ultrasonic sensors can get distance measurements. The longer the distance, the slower they are at reporting the distance. The second weakness comes from the way sound bounces off of objects. In enclosed spaces it is possible, if not probable that there will be unintended echos. The echos can very easily cause false short readings. In Figure 2 a pulse was sent out. It bounced off of object 1 and returned to the sensor. The distance was recorded and then a new pulse was sent. There was another object farther away, so that when the new pulse reaches object 1, the first signal will reach the sensor. This will cause the sensor to think that there is an object closer than is actually true. The old pulse is smaller than the new pulse because it has grown weaker. The longer the pulse exists the weaker it grows until it is negligible. If multiple sensors are being used, the number of echos will increase along with the number of errors. There are two main ways to reduce the number of errors. The first is to provide shielding around the sensor. This prevents echos coming in from angle outside what the sensor should actually pick up. The second is to reduce the frequency at which pulses are sent out. This gives more time for the echos to dissipate.

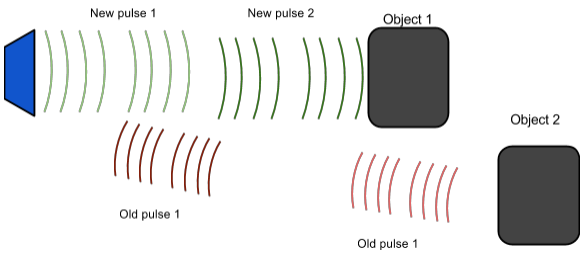
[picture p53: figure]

Works Cited

Source 1.
“HC-SR04 User's_Manual.” docs.google. Cytron Technologies, May 2013 Web. 5 Dec. 2009.
<https://docs.google.com/document/d/1Y-yZnNhMYy7rwhAgyL_pfa39RsB-x2qR4vP8saG73rE/edit>

Source 2.
“Attiny2313 Ultrasonic distance (HR-SR04) example.” CircuitDB. n.a. 7 Sept. 2014 Web. 5 Dec. 2014. <http://www.circuitdb.com/?p=1162>

Links

These are not formatted; you will need to copy and paste them into your web browser.

Want to learn about Ultrasonic Sensors in general? http://www.sensorsmag.com/sensors/acousticultrasound/choosingultrasonicsensorprox imityordistancemeasurement-825

All about the HC-SR04

- http://www.circuitdb.com/?p=1162
- http://www.micropik.com/PDF/HCSR04.pdf
- http://randomnerdtutorials.com/completeguideforultrasonicsensorhcsr04/
- http://www.ezdenki.com/ultrasonic.php
(^fantastic tutorial, explains a lot of stuff)
- http://www.elecrow.com/hcsr04-ultrasonicrangingsensorp-316.html
(^ this one has some cool charts)

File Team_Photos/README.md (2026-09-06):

# 👥 Team Photos

This folder contains photos of **Team RCBC**, capturing our team spirit, collaboration, and hardware development process throughout the WRO Future Engineers project.

---

## 📸 Photo List

### 🛠️ Team at Work - `During_Work.jpeg`
**Focus: Lab Collaboration & Development**
- Team members working together on robot assembly, sensor testing, and software integration in the lab.

<div align="center">
  Team RCBC Working in Lab
</div>

---

## 📝 Notes
- High-resolution photos documenting our engineering process and teamwork.
- For video demonstrations and updates, visit our 🎥 [YouTube Channel](https://www.youtube.com/@WRO_RCBC_EGYPT).

---

### 🔗 Related Documentation
- 🏎️ **Vehicle Photos & Layout**: [Car Photos Documentation](../Car_Photos/README.md)
- ⚙️ **Mechanical Systems**: [Mechanical Design Documentation](../Mechanical_Design/README.md)
- 👥 **Team Details**: [Main Documentation](../README.md#the-team)

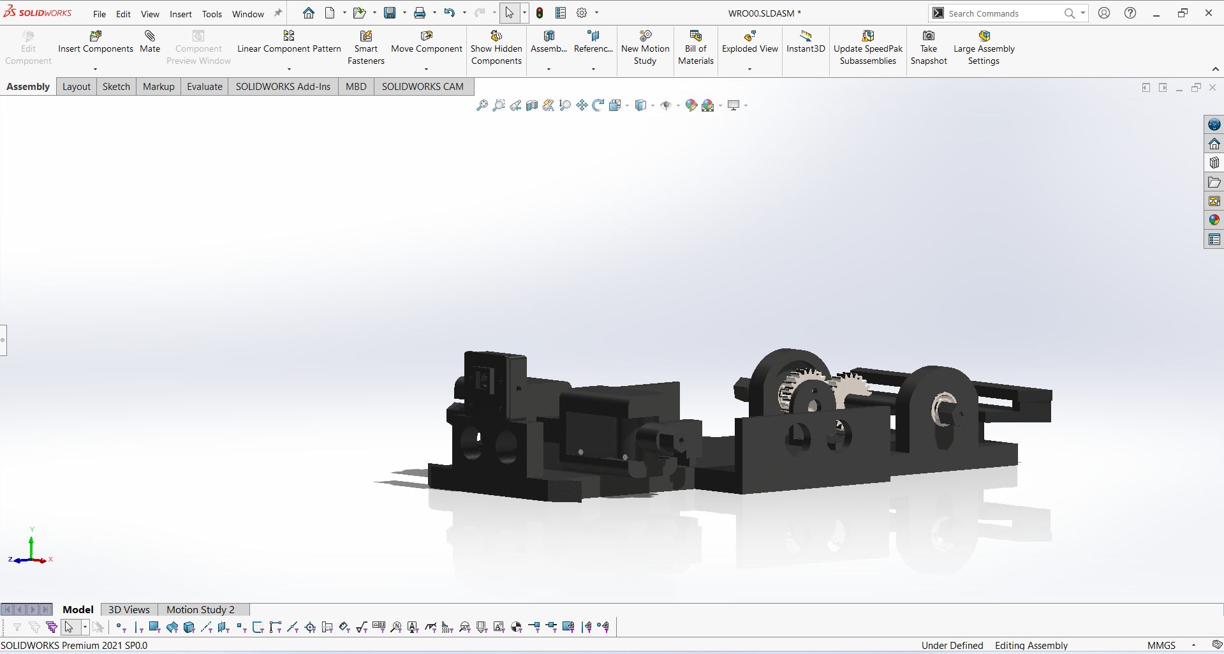
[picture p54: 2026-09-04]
Mechanical_Design/Closer Side Look.png

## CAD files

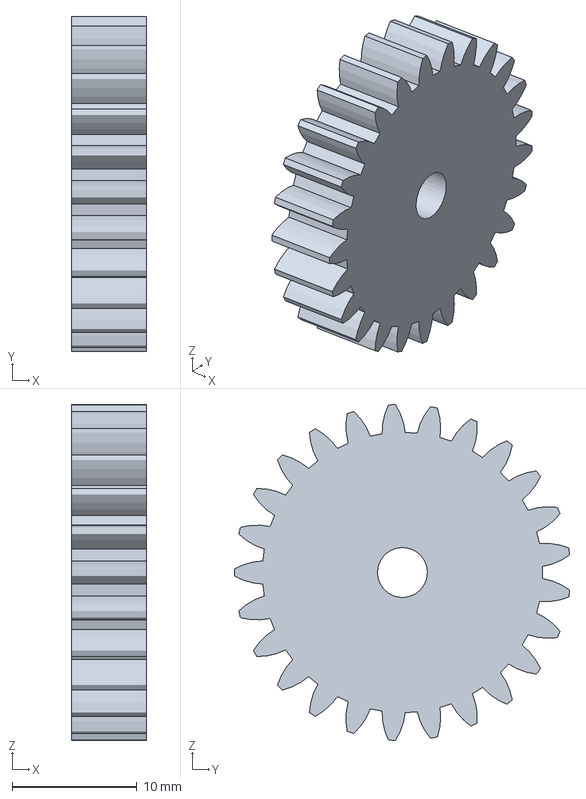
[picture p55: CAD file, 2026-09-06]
Mechanical_Design/spur gear_am.3MF
6.00 x 26.9 x 27.0 mm

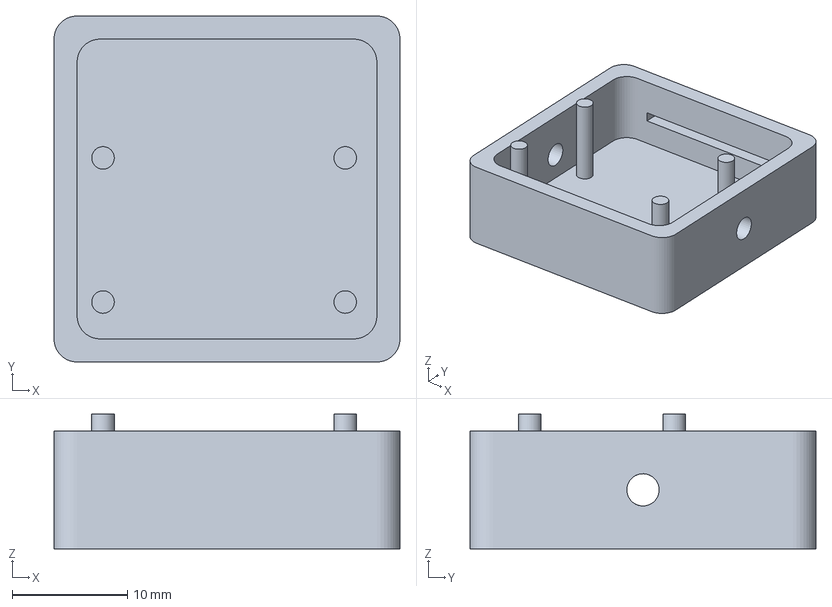
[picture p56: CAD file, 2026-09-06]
Mechanical_Design/camera casing 1.3MF
30.0 x 30.0 x 11.7 mm

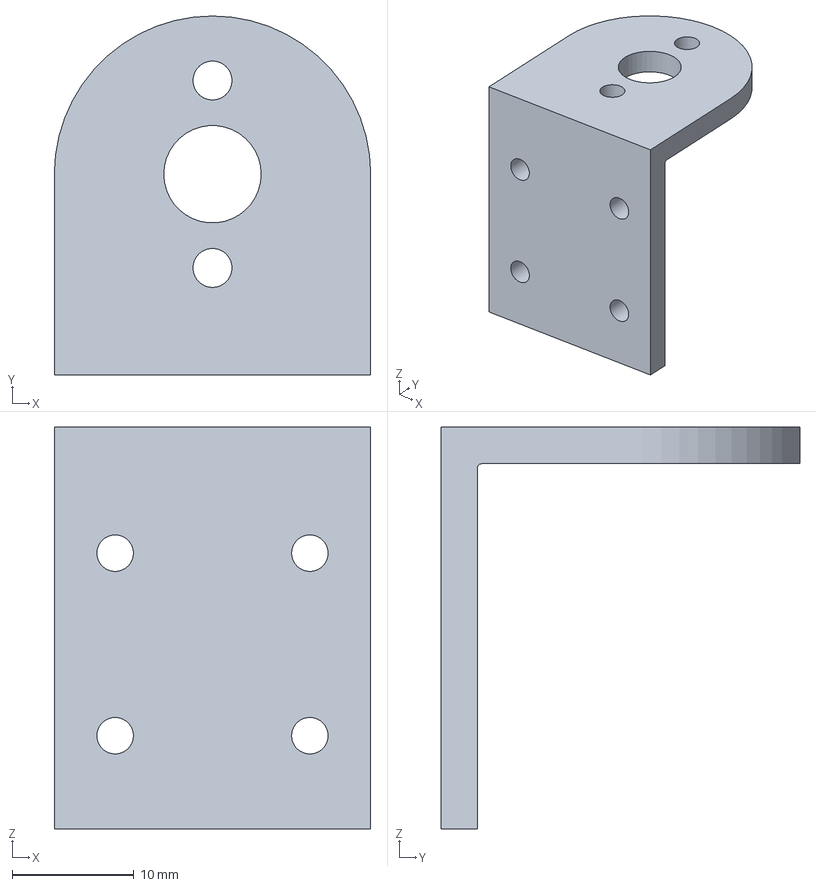
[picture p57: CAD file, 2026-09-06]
Mechanical_Design/JGA25-370 motor bracket.step.3MF
26.0 x 29.5 x 33.0 mm

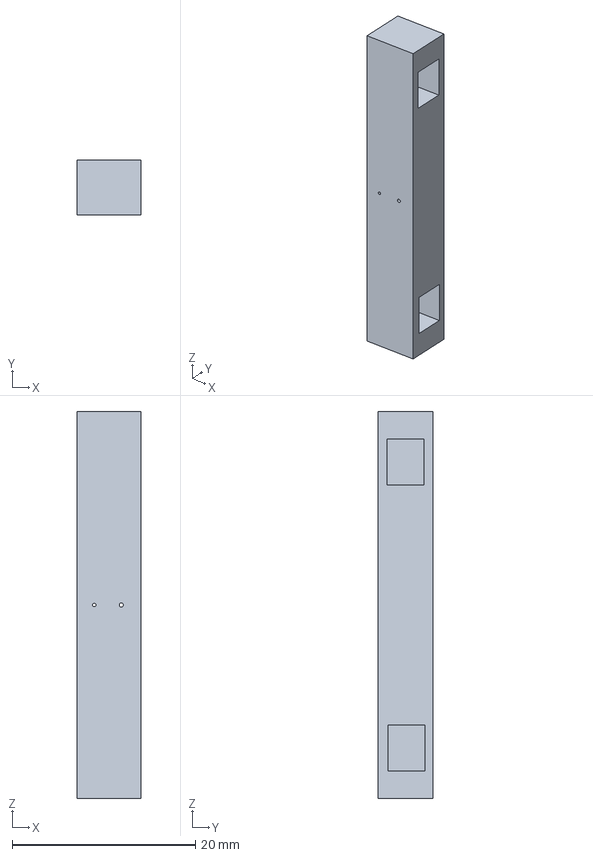
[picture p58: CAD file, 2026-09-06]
Mechanical_Design/Servo_Connector.3MF
7.00 x 6.00 x 42.2 mm

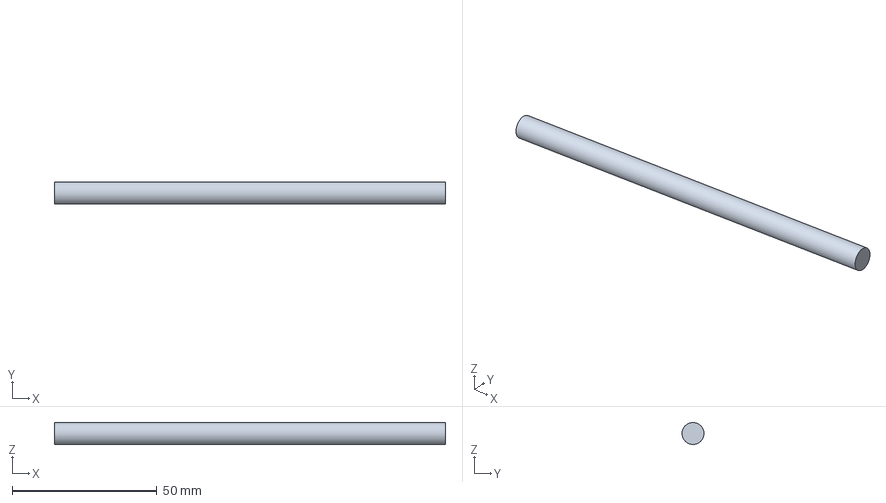
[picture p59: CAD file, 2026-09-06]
Mechanical_Design/Shaft.3MF
135.0 x 7.59 x 7.60 mm

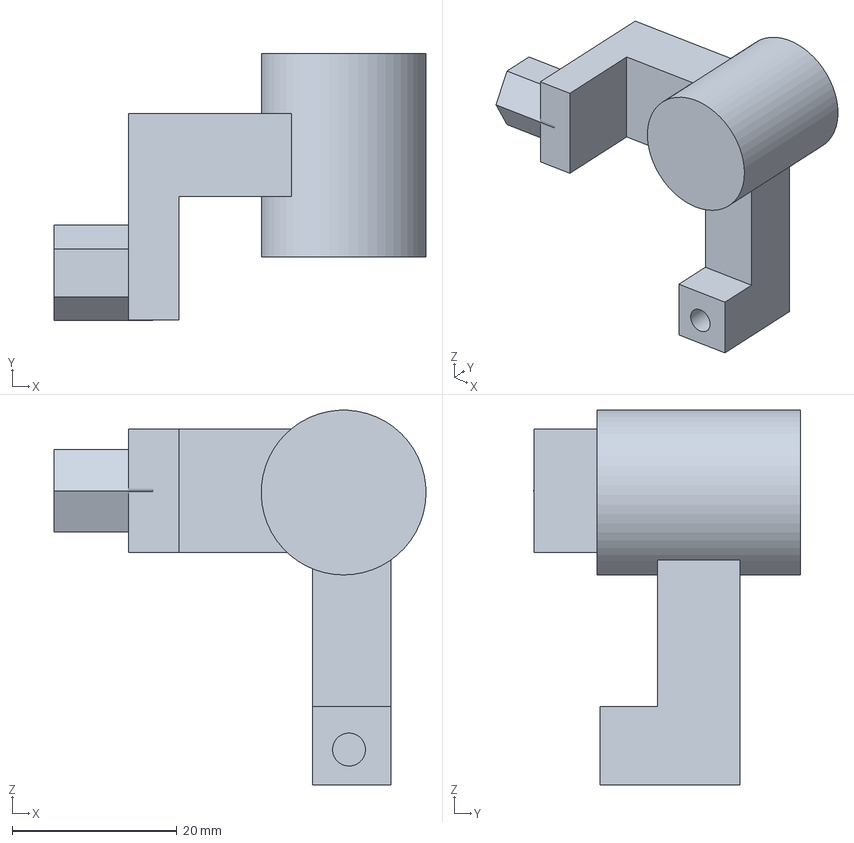
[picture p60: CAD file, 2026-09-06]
Mechanical_Design/Rotation_Right.3MF
45.1 x 32.4 x 45.5 mm

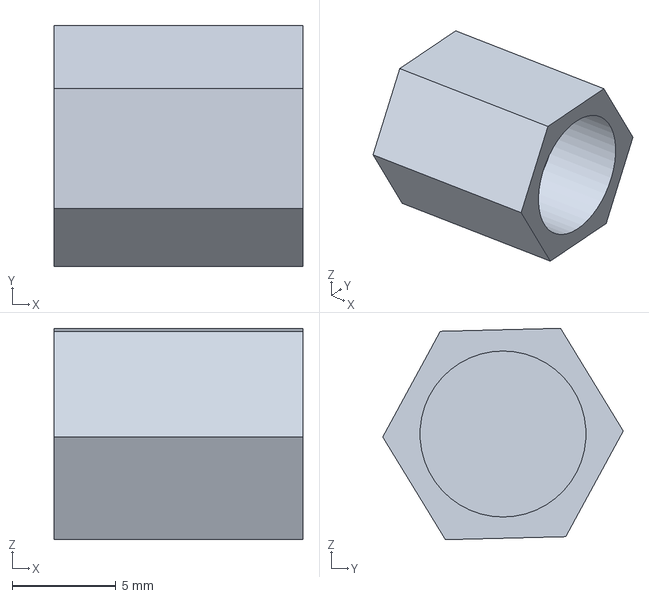
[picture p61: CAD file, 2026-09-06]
Mechanical_Design/Knuckle_Joint_boze.3MF
12.0 x 11.6 x 10.2 mm

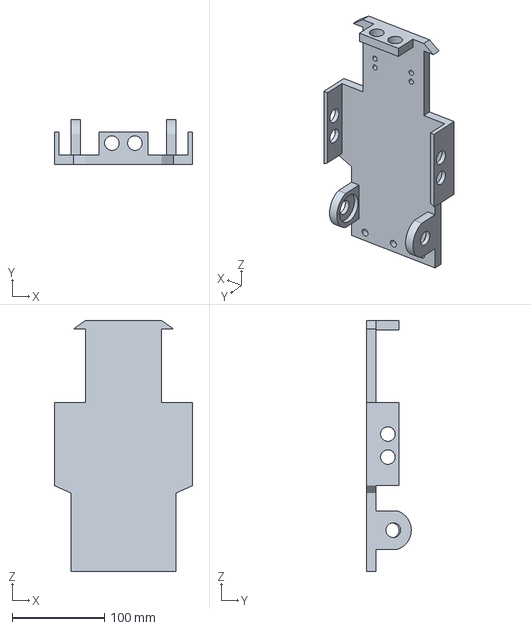
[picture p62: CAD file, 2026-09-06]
Mechanical_Design/RCBC Chassis.3MF
150.0 x 48.4 x 272.5 mm

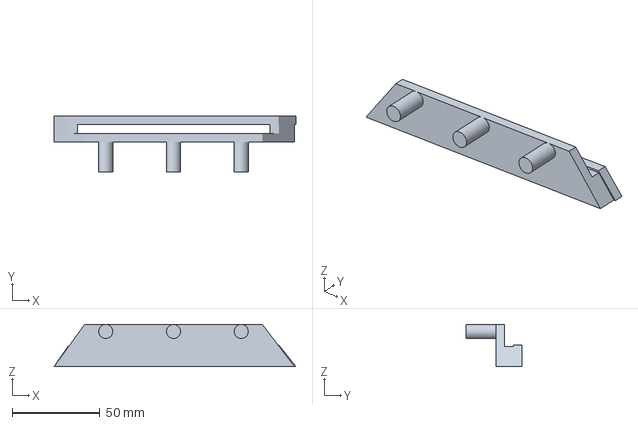
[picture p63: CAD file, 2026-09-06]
Mechanical_Design/spoiler.3MF
137.6 x 32.0 x 24.0 mm

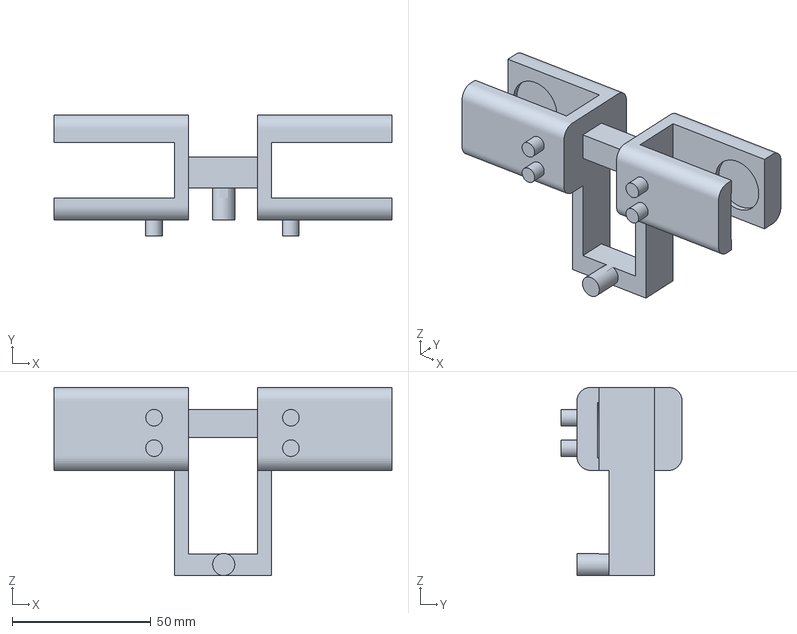
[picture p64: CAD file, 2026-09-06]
Mechanical_Design/Ackerman Axle.3MF
122.0 x 43.8 x 68.0 mm

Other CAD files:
Mechanical_Design/Rotation_Left.3MF

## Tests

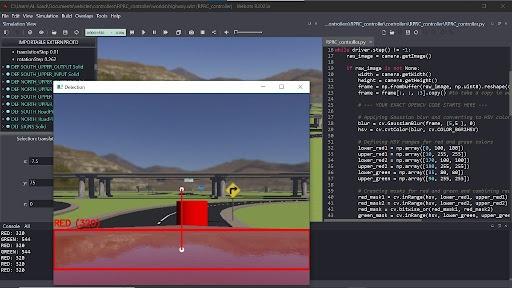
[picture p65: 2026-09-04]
colors/Testing_The_Detection_code.jpg

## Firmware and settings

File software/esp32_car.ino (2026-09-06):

#include <ESP32Servo.h>

// ======================================================
//                    PIN DEFINITIONS
// ======================================================

// Ultrasonic Sensors
#define TRIG_FRONT 4
#define ECHO_FRONT 5

#define TRIG_LEFT  18
#define ECHO_LEFT  19

#define TRIG_RIGHT 21
#define ECHO_RIGHT 22

// DC Motor Control (L298N / Driver)
#define IN1        27
#define IN2        26
#define MOTOR_PWM  14

// Servo Motor Control
#define SERVO_PIN  13


// ======================================================
//                    STEERING SETTINGS
// ======================================================

const int STEERING_CENTER    = 90;
const int STEERING_MAX_LEFT  = 55;
const int STEERING_MAX_RIGHT = 125;


// ======================================================
//              SPEED SETTINGS (SLIGHTLY FASTER)
// ======================================================

const int SPEED_NORMAL    = 135;  
const int SPEED_CORNER    = 95;   
const int SPEED_OBSTACLE  = 100;  
const int SPEED_CLEARANCE = 135;  


// ======================================================
//                    WALL FOLLOWING
// ======================================================

const float TARGET_DIST     = 20.0;
const float WALL_DEADBAND   = 2.0;
const int WALL_CORRECTION   = 18;


// ======================================================
//                    CORNER SETTINGS
// ======================================================

const float FRONT_CORNER_DIST = 60.0;
const float FRONT_CLEAR_DIST  = 75.0;

const unsigned long MIN_CORNER_TIME = 250;
const unsigned long MAX_CORNER_TIME = 1000;

unsigned long cornerStartTime = 0;
int cornerDirection = STEERING_CENTER;
bool inCorner = false;


// ======================================================
//                    VISION & OBSTACLE DATA
// ======================================================

char visionMode       = 'N';  
char obstacleColor    = 'N';
float obstacleError   = 0.0;
float obstacleDistance = 0.0;
int visionSteerAngle  = 90;

float visionLeftArea  = 0.0;
float visionRightArea = 0.0;
int visionTurnCount   = 0;

// Parking marker data (received from vision over UART, header 'M').
// Stored only — no parking maneuver logic is implemented yet.
bool  parkingMarkersFound = false;
float parkingGapError     = 0.0;
float parkingGapWidth     = 0.0;

unsigned long lastObstacleTime = 0;
const unsigned long CLEARANCE_TIME = 500;

unsigned long lastVisionTime = 0;
const unsigned long VISION_TIMEOUT = 500;


// ======================================================
//                    SENSOR FILTERS
// ======================================================

float distFront = 400.0;
float distLeft  = 400.0;
float distRight = 400.0;

float filteredLeft  = 400.0;
float filteredRight = 400.0;

bool filterInitialized = false;
const float FILTER_ALPHA = 0.30;


// ======================================================
//                    SERVO OBJECT
// ======================================================

Servo steeringServo;


// ======================================================
//              ULTRASONIC SENSOR FUNCTION
// ======================================================

float getUltrasonicDistance(int trigPin, int echoPin)
{
    digitalWrite(trigPin, LOW);
    delayMicroseconds(2);

    digitalWrite(trigPin, HIGH);
    delayMicroseconds(10);

    digitalWrite(trigPin, LOW);

    long duration = pulseIn(echoPin, HIGH, 25000);

    if (duration == 0)
        return 400.0;

    return (duration * 0.0343) / 2.0;
}


// ======================================================
//                    READ ALL SENSORS
// ======================================================

void readAllSensors()
{
    float rawFront = getUltrasonicDistance(TRIG_FRONT, ECHO_FRONT);
    float rawLeft  = getUltrasonicDistance(TRIG_LEFT, ECHO_LEFT);
    float rawRight = getUltrasonicDistance(TRIG_RIGHT, ECHO_RIGHT);

    if (!filterInitialized)
    {
        distFront = rawFront;
        filteredLeft = rawLeft;
        filteredRight = rawRight;
        distLeft = rawLeft;
        distRight = rawRight;
        filterInitialized = true;
        return;
    }

    distFront     = 0.35 * rawFront + 0.65 * distFront;
    filteredLeft  = FILTER_ALPHA * rawLeft + (1.0 - FILTER_ALPHA) * filteredLeft;
    filteredRight = FILTER_ALPHA * rawRight + (1.0 - FILTER_ALPHA) * filteredRight;

    distLeft  = filteredLeft;
    distRight = filteredRight;
}


// ======================================================
//             READ & PARSE VISION DATA (SERIAL)
// ======================================================

void readVisionData()
{
    while (Serial.available() > 0)
    {
        String data = Serial.readStringUntil('\n');
        data.trim();

        if (data.length() == 0)
            continue;

        char header = data.charAt(0);
        visionMode = header;

        if (header == 'A')
        {
            sscanf(data.c_str(), "A,%f,%f,%f,%d,%d",
                   &visionLeftArea,
                   &visionRightArea,
                   &obstacleError,
                   &visionSteerAngle,
                   &visionTurnCount);

            obstacleColor = 'N';
            lastVisionTime = millis();
        }
        else if (header == 'R' || header == 'G' || header == 'B')
        {
            char col;
            sscanf(data.c_str(), "%c,%f,%f,%d",
                   &col,
                   &obstacleError,
                   &obstacleDistance,
                   &visionSteerAngle);

            obstacleColor = col;
            lastVisionTime = millis();
        }
        else if (header == 'C')
        {
            obstacleColor = 'C';
            sscanf(data.c_str(), "C,%f", &obstacleError);
            lastVisionTime = millis();
        }
        else if (header == 'M')
        {
            // Parking-gap data from the magenta markers.
            // Parsed and stored only — no maneuver is triggered here.
            int found = 0;
            sscanf(data.c_str(), "M,%d,%f,%f", &found, &parkingGapError, &parkingGapWidth);
            parkingMarkersFound = (found == 1);
            lastVisionTime = millis();
        }
        else if (header == 'N')
        {
            obstacleColor = 'N';
            obstacleDistance = 0.0;
            obstacleError = 0.0;
            visionSteerAngle = STEERING_CENTER;
            lastVisionTime = millis();
        }
    }

    if (millis() - lastVisionTime > VISION_TIMEOUT)
    {
        obstacleColor = 'N';
        visionMode = 'N';
    }
}


// ======================================================
//                    MOTOR CONTROL
// ======================================================

void setMotor(int speed, bool forward)
{
    speed = constrain(speed, 0, 255);

    if (forward)
    {
        digitalWrite(IN1, HIGH);
        digitalWrite(IN2, LOW);
    }
    else
    {
        digitalWrite(IN1, LOW);
        digitalWrite(IN2, HIGH);
    }

    analogWrite(MOTOR_PWM, speed);
}

void stopMotor()
{
    digitalWrite(IN1, LOW);
    digitalWrite(IN2, LOW);
    analogWrite(MOTOR_PWM, 0);
}


// ======================================================
//                    SERVO CONTROL
// ======================================================

void setSteering(int angle)
{
    int clampedAngle = constrain(angle, STEERING_MAX_LEFT, STEERING_MAX_RIGHT);
    int invertedAngle = 180 - clampedAngle;
    steeringServo.write(invertedAngle);
}

void centerSteering()
{
    setSteering(STEERING_CENTER);
}


// ======================================================
//                    CORNER LOGIC
// ======================================================

void startCorner()
{
    if (inCorner) return;

    inCorner = true;
    cornerStartTime = millis();

    if (distRight > distLeft)
        cornerDirection = STEERING_MAX_RIGHT;
    else
        cornerDirection = STEERING_MAX_LEFT;
}

bool handleCorner()
{
    if (!inCorner) return false;

    unsigned long elapsed = millis() - cornerStartTime;

    if (elapsed > MAX_CORNER_TIME)
    {
        inCorner = false;
        centerSteering();
        return false;
    }

    setSteering(cornerDirection);
    setMotor(SPEED_CORNER, true);

    if (elapsed < MIN_CORNER_TIME)
        return true;

    if (distFront > FRONT_CLEAR_DIST)
    {
        inCorner = false;
        centerSteering();
        return false;
    }

    return true;
}

void detectCorner()
{
    if (inCorner) return;

    if (distFront > 0 && distFront < FRONT_CORNER_DIST)
    {
        startCorner();
    }
}


// ======================================================
//                VISION OBSTACLE AVOIDANCE
// ======================================================

bool handleVisionObstacle()
{
    if (obstacleColor == 'N')
        return false;

    if (obstacleDistance <= 0 || obstacleDistance > 50)
        return false;

    if (obstacleColor == 'R')
    {
        lastObstacleTime = millis();
        setSteering(STEERING_MAX_RIGHT);
        setMotor(SPEED_OBSTACLE, true);
        return true;
    }

    if (obstacleColor == 'G')
    {
        lastObstacleTime = millis();
        setSteering(STEERING_MAX_LEFT);
        setMotor(SPEED_OBSTACLE, true);
        return true;
    }

    return false;
}


// ======================================================
//                  CLEARANCE STATE
// ======================================================

bool clearanceState()
{
    if (millis() - lastObstacleTime < CLEARANCE_TIME)
    {
        centerSteering();
        setMotor(SPEED_CLEARANCE, true);
        return true;
    }
    return false;
}


// ======================================================
//               WALL & AREA VISION FOLLOWING
// ======================================================

void wallFollowing()
{
    int steering = STEERING_CENTER;

    if (visionMode == 'A')
    {
        steering = visionSteerAngle;
    }
    else
    {
        if (distRight < 70.0 && distLeft >= 70.0)
        {
            float error = distRight - TARGET_DIST;
            if (abs(error) <= WALL_DEADBAND)
                steering = STEERING_CENTER;
            else if (error > 0)
                steering = STEERING_CENTER + WALL_CORRECTION;
            else
                steering = STEERING_CENTER - WALL_CORRECTION;
        }
        else if (distLeft < 70.0 && distRight >= 70.0)
        {
            float error = distLeft - TARGET_DIST;
            if (abs(error) <= WALL_DEADBAND)
                steering = STEERING_CENTER;
            else if (error > 0)
                steering = STEERING_CENTER - WALL_CORRECTION;
            else
                steering = STEERING_CENTER + WALL_CORRECTION;
        }
        else if (distLeft < 70.0 && distRight < 70.0)
        {
            float centerError = distLeft - distRight;
            if (abs(centerError) > 2.0)
                steering = STEERING_CENTER - (int)(centerError * 2.0);
            else
                steering = STEERING_CENTER;
        }
    }

    setSteering(steering);
    setMotor(SPEED_NORMAL, true);
}


// ======================================================
//                        SETUP
// ======================================================

void setup()
{
    Serial.begin(115200);
    // Prevents readStringUntil() in readVisionData() from blocking the main
    // loop for up to the default 1000ms if a line arrives without its '\n'
    // terminator (communication-layer fix only — no driving logic changed).
    Serial.setTimeout(10);

    pinMode(TRIG_FRONT, OUTPUT);
    pinMode(ECHO_FRONT, INPUT);

    pinMode(TRIG_LEFT, OUTPUT);
    pinMode(ECHO_LEFT, INPUT);

    pinMode(TRIG_RIGHT, OUTPUT);
    pinMode(ECHO_RIGHT, INPUT);

    pinMode(IN1, OUTPUT);
    pinMode(IN2, OUTPUT);
    pinMode(MOTOR_PWM, OUTPUT);

    ESP32PWM::allocateTimer(0);
    ESP32PWM::allocateTimer(1);
    ESP32PWM::allocateTimer(2);
    ESP32PWM::allocateTimer(3);

    steeringServo.setPeriodHertz(50);
    steeringServo.attach(SERVO_PIN, 500, 2500);

    centerSteering();
    stopMotor();
    lastVisionTime = millis();

    delay(1000);
}


// ======================================================
//                      MAIN LOOP
// ======================================================

void loop()
{
    readAllSensors();
    readVisionData();

    if (handleVisionObstacle())
    {
        delay(15);
        return;
    }

    if (clearanceState())
    {
        delay(15);
        return;
    }

    if (handleCorner())
    {
        delay(15);
        return;
    }

    detectCorner();
    if (inCorner)
    {
        handleCorner();
        delay(15);
        return;
    }

    wallFollowing();

    if (visionTurnCount >= 12)
    {
        stopMotor();
        while (true) {
            // Stop vehicle upon completing 3 laps
        }
    }

    delay(15);
}

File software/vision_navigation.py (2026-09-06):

import cv2 as cv
import numpy as np
import serial 


# 1. Initialization & Setup


# esp32 = serial.Serial('COM3', 115200, timeout=0.1) 

capture = cv.VideoCapture(0)
kernel = np.ones((5, 5), np.uint8)

# Control parameters
kp = 0.05               
offset_multiplier = 1.5 

while True:
    ret, frame = capture.read()
    if not ret:
        break
        
    
    # 2. Image Preprocessing
    
    blur = cv.GaussianBlur(frame, (5, 5), 0)
    hsv = cv.cvtColor(blur, cv.COLOR_BGR2HSV)
    
    h, w = frame.shape[:2]
    frame_center_x = w // 2 
    
    #  HSV Bounds 
    # Traffic Signs 
    lower_red1, upper_red1 = np.array([0, 100, 100]), np.array([10, 255, 255])
    lower_red2, upper_red2 = np.array([170, 100, 100]), np.array([180, 255, 255])
    lower_green, upper_green = np.array([35, 80, 80]), np.array([90, 255, 255])
    
    # Track Navigation: Masking the White Floor (Drivable Area between Black Walls)
    # Adjust these thresholds based on the venue's lighting conditions
    lower_lane = np.array([0, 0, 200])      # High value/brightness for white floor
    upper_lane = np.array([180, 50, 255])

    # Parking lot limiters (RGB 255,0,255 -> magenta hue band in OpenCV's 0-179 scale)
    lower_magenta = np.array([140, 100, 100])
    upper_magenta = np.array([165, 255, 255])
    
    # --- Masks Creation ---
    red_mask = cv.bitwise_or(cv.inRange(hsv, lower_red1, upper_red1), 
                             cv.inRange(hsv, lower_red2, upper_red2))
    green_mask = cv.inRange(hsv, lower_green, upper_green)
    lane_mask = cv.inRange(hsv, lower_lane, upper_lane)
    magenta_mask = cv.inRange(hsv, lower_magenta, upper_magenta)
    
    # Morphology (Noise Removal)
    red_mask = cv.morphologyEx(red_mask, cv.MORPH_OPEN, kernel)
    green_mask = cv.morphologyEx(green_mask, cv.MORPH_OPEN, kernel)
    lane_mask = cv.morphologyEx(lane_mask, cv.MORPH_OPEN, kernel)
    magenta_mask = cv.morphologyEx(magenta_mask, cv.MORPH_OPEN, kernel)
    
    
    # 3. ROI (Region of Interest) for Track Floor Tracking
    
    # Ignore the top half of the frame to avoid detecting ambient light outside the field
    roi_top_boundary = h // 2
    lane_mask[0:roi_top_boundary, :] = 0 
    
    # 4. State Machine & Object Detection
    
    red_contours, _ = cv.findContours(red_mask, cv.RETR_EXTERNAL, cv.CHAIN_APPROX_SIMPLE)
    green_contours, _ = cv.findContours(green_mask, cv.RETR_EXTERNAL, cv.CHAIN_APPROX_SIMPLE)
    lane_contours, _ = cv.findContours(lane_mask, cv.RETR_EXTERNAL, cv.CHAIN_APPROX_SIMPLE)

    target_cx = None 
    action_text = "LOST (STOP)" 

    # STATE 1: Avoid Red Pillar -> Keep to the Right Side [WRO Rule 5]
    if red_contours and cv.contourArea(max(red_contours, key=cv.contourArea)) > 1000:
        contour = max(red_contours, key=cv.contourArea)
        x, y, bw, bh = cv.boundingRect(contour)
        if (cv.contourArea(contour) / (bw * bh)) > 0.5:
            cx = x + bw // 2
            cy = y + bh // 2
            target_cx = cx - int(bw * offset_multiplier) # Shift path to the left of the pillar
            action_text = "AVOID RED"
            cv.rectangle(frame, (x, y), (x + bw, y + bh), (0, 0, 255), 3)
            cv.circle(frame, (target_cx, cy), 8, (255, 0, 0), -1)

    # STATE 2: Avoid Green Pillar -> Keep to the Left Side [WRO Rule 5]
    elif green_contours and cv.contourArea(max(green_contours, key=cv.contourArea)) > 1000:
        contour = max(green_contours, key=cv.contourArea)
        x, y, bw, bh = cv.boundingRect(contour)
        if (cv.contourArea(contour) / (bw * bh)) > 0.5:
            cx = x + bw // 2
            cy = y + bh // 2
            target_cx = cx + int(bw * offset_multiplier) # Shift path to the right of the pillar
            action_text = "AVOID GREEN"
            cv.rectangle(frame, (x, y), (x + bw, y + bh), (0, 255, 0), 3)
            cv.circle(frame, (target_cx, cy), 8, (255, 0, 0), -1)

    # STATE 3: Center on White Track Floor (Default when no pillars are visible)
    elif lane_contours:
        contour = max(lane_contours, key=cv.contourArea)
        if cv.contourArea(contour) > 500: 
            # Calculate the center of mass of the visible white floor section
            M = cv.moments(contour)
            if M['m00'] > 0:
                cx = int(M['m10'] / M['m00'])
                cy = int(M['m01'] / M['m00'])
                target_cx = cx # Target is the exact center of the white drivable corridor
                action_text = "CENTER ON TRACK"
                
                # Visual feedback of the calculated corridor center
                cv.drawContours(frame, [contour], -1, (255, 255, 0), 2)
                cv.circle(frame, (cx, cy), 8, (255, 255, 0), -1)

    # STATE 4: Parking marker detection (runs every frame, independent of the
    # driving state above - the ESP32 decides when to act on it, only after
    # it has counted 3 completed laps).
    magenta_contours, _ = cv.findContours(magenta_mask, cv.RETR_EXTERNAL, cv.CHAIN_APPROX_SIMPLE)

    marker_centers = []
    for cnt in magenta_contours:
        area = cv.contourArea(cnt)
        if area > 150:  # tune: markers look small in frame from a distance
            mx, my, mw, mh = cv.boundingRect(cnt)
            marker_centers.append(mx + mw // 2)
            cv.rectangle(frame, (mx, my), (mx + mw, my + mh), (255, 0, 255), 2)
    marker_centers.sort()

    if len(marker_centers) >= 2:
        left_marker, right_marker = marker_centers[0], marker_centers[-1]
        gap_center = (left_marker + right_marker) // 2
        gap_error = gap_center - frame_center_x   # +ve = gap sits right of centre
        gap_width = right_marker - left_marker
        both_markers_found = 1
        cv.putText(frame, f"PARKING GAP | Err: {gap_error} W: {gap_width}",
                   (10, 60), cv.FONT_HERSHEY_SIMPLEX, 0.6, (255, 0, 255), 2)
    else:
        gap_error = 0
        gap_width = 0
        both_markers_found = 0

    # Send to ESP32 - matches the "M,<found>,<gapError>,<gapWidth>" case
    # added to readVisionData() in control.ino.
    # esp32.write(f"M,{both_markers_found},{gap_error},{gap_width}\n".encode('utf-8'))
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

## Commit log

2026-09-05 Rename Screenshot 2026-09-04 185724.png to RCBC's Chassis.jpg
2026-09-06 Rename Screenshot 2026-09-04 201801.png to Final View Of The Chassis.png
2026-09-06 Rename Screenshot 2026-09-04 194209.png to Front View With The Camera .png
2026-09-06 Rename Screenshot 2026-09-04 193644.png to Gear System.png
2026-09-06 Rename Screenshot 2026-09-04 194407.png to Ackerman Steering.png
